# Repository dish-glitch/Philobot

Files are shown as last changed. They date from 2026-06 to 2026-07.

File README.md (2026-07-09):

# Philo — Autonomous Person-Following Robot

**A 4-wheeled ground robot that locks onto a person using real-time YOLOv8 pose detection and follows them across a room. Raise your hand and it stops. Lower it and it follows again.**








---

## Schematic Preview



---

## PCB Preview



---

## Chassis Preview

*Coming soon — Fusion 360 render in progress*

---

## What It Does

A Raspberry Pi 5 runs YOLOv8 pose estimation on a live camera feed, detects the nearest person in frame, and continuously streams direction and speed commands to an ESP32 over UART. The ESP32 runs closed-loop PID speed control on four DC motors via dual H-bridge drivers. Three ultrasonic sensors on the front of the chassis act as an independent safety layer — if an obstacle is detected under 25cm, the ESP32 overrides the Pi command and stops regardless of what the vision stack says.

**Gesture control:** YOLOv8 tracks 17 body keypoints per person. When either wrist keypoint rises above the shoulder keypoint in frame coordinates, the Pi switches to STOP mode and holds it for 5 consecutive frames before acting — this debounces the detection and prevents flickering. Lowering the hand for 5 consecutive frames resumes following. Stop gesture confirmed working in testing.

**Sign language recognition:** The camera detects ASL hand signs in real time using MediaPipe hand landmarks and a trained classifier. Recognized letters are sent over UART to the ESP32 and displayed live on the onboard OLED (bench-tested on the Arduino stand-in; the ESP32 `ASL` handler is implemented and awaiting PCB bring-up). Initial testing on Pi 5 shows strong results for most letters — broader testing across different hands, lighting, and environments is still in progress.

**Obstacle avoidance:** Three HC-SR04 ultrasonic sensors (front-left at -30 degrees, front-center, front-right at +30 degrees) feed into a priority layer in ESP32 firmware. The Pi handles direction. The ESP32 handles not hitting things. These are separate concerns and intentionally kept that way.

---

## How It Works

```
+--------------------------------------------------+
|              Raspberry Pi 5                      |
|                                                  |
|  Camera -> YOLOv8n-pose -> keypoint extraction   |
|               |                                  |
|      Person bounding box offset                  |
|      Wrist vs. shoulder Y position               |
|               |                                  |
|      State machine (FOLLOWING / WAITING)         |
|               |                                  |
|      Serial command -> UART TX                   |
+---------------+----------------------------------+
                |  115200 baud UART
                |  Format: CMD <left> <right> <flags>  (-255..255)
                v
+--------------------------------------------------+
|              ESP32-WROOM-32                      |
|                                                  |
|  UART RX -> parse command                        |
|               |                                  |
|  Ultrasonic check (priority override)            |
|               |                                  |
|  PID speed control per motor side                |
|  PWM via LEDC peripheral at 20kHz               |
|               |                                  |
|  TB6612FNG x2 -> 4 DC motors with encoders      |
+--------------------------------------------------+
```

**Latency budget (targets):**

| Stage | Target |
|---|---|
| Camera capture | ~5ms |
| YOLOv8n-pose inference (imgsz=320) | ~70ms |
| Serial transmission | ~1ms |
| ESP32 motor response | ~5ms |
| **Total loop** | **~80ms (~12 Hz)** |

12 Hz is sufficient for following a walking person. A running person would expose the lag — but that is not the use case.

**Why UART and not I2C or SPI:** UART is asynchronous and trivially debuggable with a serial monitor. I2C requires the ESP32 to act as master which complicates the Pi-side code. SPI is faster than needed. UART at 115200 baud moves our 20-byte command packets in under 2ms. It is the right tool for this interface.

**Why TB6612FNG and not L298N:** The L298N drops ~2V across its internal transistors at 1A, wasting power as heat and requiring a heatsink. The TB6612FNG is a MOSFET H-bridge — nearly zero voltage drop, no heatsink needed, physically smaller. It is the correct motor driver for battery-powered mobile robots.

**Why YOLOv8n-pose and not separate detection and pose models:** One model pass gives you person detection and 17 keypoints simultaneously. Running two models would double inference time and add synchronization complexity. The nano pose model is marginally slower than nano detect-only and eliminates the entire second pipeline.

---

## Hardware

> Prices are estimates. Amazon prices fluctuate — verify before ordering. Order DigiKey parts together to share one flat shipping fee (~$8).

| Component | Purpose | Qty | Est. Price | Where |
|---|---|---|---|---|
| ESP32-WROOM-32 | Main MCU | 1 | ~$5 | Amazon |
| TB6612FNG Dual H-Bridge (bare IC, SSOP-24) | Motor driver (2 motors each) | 2 | ~$2 ea | DigiKey |
| MPU-6050 IMU | Tilt detection, auto-stop on tip-over | 1 | ~$2 | Amazon |
| JGA25-370 Gear Motors w/ Encoders (6V 200RPM) | Drive wheels | 4 | ~$8 ea | AliExpress |
| 80mm Rubber Wheels | Traction | 4 | ~$3 ea | AliExpress |
| HC-SR04 Ultrasonic Sensors | Obstacle detection | 3 | ~$1 ea | Amazon |
| SSD1306 OLED 0.96" I2C | Eyes + ASL display on mast | 2 | ~$4 ea | Amazon |
| 2S LiPo 2200mAh | Main battery | 1 | ~$14 | Amazon / HobbyKing |
| 2S LiPo Balance Charger | Charging | 1 | ~$10 | Amazon |
| Raspberry Pi 5 (4GB) | Vision compute | 1 | on hand | From friend — with active cooler |
| Raspberry Pi Camera Module 3 | 12MP, autofocus | 1 | on hand | Attached, confirmed working |
| AMS1117-3.3 LDO | 3.3V rail for ESP32 logic | 1 | ~$1 | DigiKey |
| Pololu D24V50F5 Buck (5V 5A) | 5V rail for Raspberry Pi | 1 | ~$30 | [Pololu](https://www.pololu.com/product/2851) |
| Littelfuse RGEF700 Polyfuse 7A | Battery overcurrent protection | 1 | ~$2 | DigiKey |
| AOD4185 P-channel MOSFET | Reverse polarity protection | 1 | ~$1 | DigiKey |
| Status LED (any 5mm) | Boot/status indicator | 1 | ~$1 | Amazon |
| Tactile switches 6mm THT | Reset + Boot buttons | 2 | ~$1 | Amazon |
| SMD Resistors 0603 assortment | Pull-ups, current limiting | — | ~$9 | Amazon |
| SMD Capacitors 0603/0805 assortment | HF decoupling bypass caps | — | ~$10 | Amazon |
| Electrolytic caps (1000µF 16V + 2×470µF 16V + 100µF 16V) | Bulk decoupling — order separately, not in SMD assortment | — | ~$5 | DigiKey |
| XT30 Connector Pair | Battery connector | 1 | ~$2 | Amazon |
| 2.54mm Pin Headers | Sensor and UART connectors | — | ~$6 | Amazon |
| CP2102 USB-UART Programmer | Flash ESP32 firmware | 1 | ~$7 | Amazon |
| Custom PCB — JLCPCB (5 boards) | From Gerbers | 1 run | ~$25 | [JLCPCB](https://jlcpcb.com) |
| PETG-CF Filament | Chassis | — | $0 | On hand |
| M2.5 / M3 Standoffs + Screws | Mounting hardware | — | ~$8 | Amazon |
| **Total** | | | **~$215** | |

---

## Repository Structure

```
Philo/
├── hardware/
│   └── kicad/
│       ├── Philo.kicad_sch           # Schematic (ESP32, motors, power, sensors)
│       ├── Philo- main.kicad_pcb     # PCB layout — 116×116mm 2-layer, 4x M3 mounting holes
│       └── gerbers/                  # Production files ready for JLCPCB
│           ├── *.gtl / *.gbl         # Front / back copper
│           ├── *.gts / *.gbs         # Solder mask
│           ├── *.gto / *.gbo         # Silkscreen
│           ├── *.gm1                 # Board outline
│           └── *.drl                 # Drill files
├── firmware/
│   ├── esp32/
│   │   ├── platformio.ini            # PlatformIO config (espressif32 6.9.0)
│   │   └── src/
│   │       ├── main.cpp              # Entry point — 10 Hz sensor + Pi loop
│   │       ├── pins.h                # All GPIO assignments (verified from netlist)
│   │       ├── motors.h / .cpp       # TB6612FNG H-bridge control (PWM via LEDC)
│   │       ├── encoders.h / .cpp     # Interrupt-based wheel encoder counting
│   │       ├── ultrasonic.h / .cpp   # HC-SR04 distance (L / C / R)
│   │       ├── imu.h / .cpp          # MPU-6050 over I²C (accel + gyro)
│   │       ├── display.h / .cpp      # SSD1306 OLED status display
│   │       └── pi_comm.h / .cpp      # UART text protocol to Raspberry Pi
│   ├── arduino/                      # Uno bench-test sketches (ESP32 stand-in)
│   └── pico/                         # Pico MicroPython bench tests (experimental)
├── mechanical/
│   ├── Philo- main.step              # 3D board export
│   ├── fusion360/                    # Chassis CAD source files
│   └── stl/                         # Print-ready STL files
├── vision/
│   └── rpi/                         # YOLOv8 + gesture + ASL + Xbox manual drive (Python)
└── docs/
    ├── images/                       # Photos, renders, wiring diagrams
    ├── PRE_BUILD_LOCK.md             # Design freeze checklist
    └── RESEARCH.md                   # Reference robots, papers, and datasheets used
```

---

## Build Log

| Date | Milestone |
|---|---|
| June 16, 2026 | Project started. Repository initialized. Team of 4 assembled. |
| June 17, 2026 | KiCad schematic started — ESP32, motor drivers, power block |
| June 21, 2026 | PCB schematic complete, ERC clean |
| June 21, 2026 | PCB layout complete, DRC clean, Gerbers exported |
| June 22, 2026 | ESP32 firmware skeleton complete — all modules compile (motors, encoders, ultrasonic, IMU, OLED, Pi UART) |
| June 22, 2026 | Gesture stop function confirmed working (tested on Arduino) |
| June 22, 2026 | Sign language recognition working for subset of letters — OLED display output confirmed |
| June 22, 2026 | Chassis design started in Fusion 360 |
| June 28, 2026 | Upgraded to Raspberry Pi 5 with active cooler — camera confirmed working |
| June 28, 2026 | YOLOv8n-pose running live on Pi 5 — person following confirmed |
| June 28, 2026 | ASL sign recognition working well for most letters in initial testing — broader validation ongoing |
| — | PCB ordered from JLCPCB |
| — | Chassis v1 printed in PETG-CF |
| — | PCB arrived, soldered, power-on test passed |
| — | Basic motor spin confirmed over serial |
| — | First person following on robot hardware |
| — | Gesture control working on robot |
| — | Obstacle avoidance tuned |
| — | Demo video filmed |
| Aug 17, 2026 | School starts — project complete |

---

## Status

- [x] KiCad schematic — complete, ERC clean
- [x] PCB layout — complete, DRC clean, Gerbers exported
- [x] ESP32 firmware skeleton — all modules compile (motors, encoders, ultrasonic, IMU, OLED, Pi UART)
- [x] ESP32 safety layer — 500ms watchdog, obstacle override, tilt cutoff, sequential ultrasonic firing (needs hardware validation)
- [x] Pi vision stack — YOLOv8 person following + gesture + ASL running on Pi 5
- [x] YOLOv8n-pose live on Pi 5 — person following confirmed working
- [x] Gesture stop — confirmed working in bench testing
- [x] ASL sign recognition — working well for most letters in initial testing; broader testing ongoing
- [ ] Gesture sensitivity tuning — currently too sensitive, fix tracked in issue #2
- [ ] PCB fabrication (JLCPCB)
- [ ] Chassis design (Fusion 360) — in progress
- [ ] Chassis printed
- [ ] PID speed loop (ESP32)
- [ ] Ultrasonic obstacle avoidance tuning
- [ ] Full system integration on robot hardware
- [ ] Demo video

---

## Team

| Person | Role |
|---|---|
| [@dish-glitch](https://github.com/dish-glitch) | PCB design (KiCad) + ESP32 firmware |
| [@sivathamizhan](https://github.com/sivathamizhan) & [@dish-glitch](https://github.com/dish-glitch) | Raspberry Pi vision stack — YOLOv8, gesture detection, serial comms |
| [@hummos430](https://github.com/hummos430) | Chassis design in Fusion 360 + 3D printing in PETG-CF |
| [@dish-glitch](https://github.com/dish-glitch), [@hummos430](https://github.com/hummos430), [@sivathamizhan](https://github.com/sivathamizhan) | Mechanical assembly + integration testing |

---

## AI Tools Used

We used Claude (Anthropic) as a reference tool during this project and are disclosing it openly. We had no robotics program, no teacher, and no mentor. AI filled the role a textbook or more experienced teammate would have filled if we'd had access to one.

**Where Claude helped:**

- Reviewing GPIO assignments from the KiCad netlist and catching wiring errors before we soldered anything
- Drafting initial ESP32 firmware modules as a starting point — the team then read through, modified, tested, and debugged everything on actual hardware
- Diagnosing a PlatformIO build failure (`pins_arduino.h` not found) caused by a version conflict between espressif32@6.9.0 and 7.0.1
- Explaining why specific hardware choices make sense (TB6612FNG vs L298N, YOLOv8n-pose vs separate models, UART vs I2C) so we could make informed decisions
- Helping structure the GitHub repository and draft documentation to a presentable structure. 
- Providing weight and dimension constraints for the chassis — specifically, what size the enclosure needs to be so the motors can actually move it. The chassis itself is fully designed by the team in Fusion 360

**What the team built and owns:**

- All hardware decisions — component selection, schematic design, and PCB layout in KiCad
- The full vision stack — YOLOv8 inference pipeline, ASL classifier, gesture detection, serial comms — written and tested by the team
- All physical testing and iteration — every debug session, hardware fix, and tuning pass was done by us in the real world
- The chassis design in Fusion 360 — built by our mechanical lead from scratch
- Every journal entry — written by the team in our own words

We are happy to answer questions about any part of this project. We have used AI to help build it, but we understand everything we built. If AI helped create any line of code or suggested a part that seemed better, we did the research to understand what that part or code does and why — before it went into the project. The reference robots, papers, and datasheets we used to back up those decisions are collected in [`docs/RESEARCH.md`](docs/RESEARCH.md).

---

## License

MIT — use, modify, share freely. See [LICENSE](LICENSE).

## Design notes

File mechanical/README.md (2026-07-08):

# Mechanical — Philo Chassis

**Owner: [@hummos430](https://github.com/hummos430) [@ezan13](https://github.com/ezan13)         **

---

## Overview

Philo uses a differential drive system — 4 wheels, split into a left side and a right side. Both wheels on the left are driven together, both wheels on the right are driven together. Turning is done by spinning the two sides at different speeds or in opposite directions. No steering axle, no servo, no complex geometry. Same drive principle as a tank or a wheelchair.

---

## How Turning Works

| Command | Left Side | Right Side | Result |
|---|---|---|---|
| Forward | Forward | Forward | Straight |
| Turn Right | Forward | Slower / Reverse | Curves or pivots right |
| Turn Left | Slower / Reverse | Forward | Curves or pivots left |
| Spin in Place | Forward | Reverse | Zero-radius pivot |
| Stop | Stop | Stop | Brakes |

The ESP32 controls each side independently via PWM. hummos430 does not need to worry about the electronics — just make sure the left two wheels are each driven by their own motor and the right two are each driven by theirs. The cable from each motor goes straight to the PCB.

---

## Real Weight Budget (Verified Component Weights)

> This section uses confirmed specifications from datasheets and product pages. These are not guesses.

| Component | Source | Confirmed Weight |
|---|---|---|
| Raspberry Pi 5 (4GB) w/ active cooler | Official spec | **51g + ~15g cooler = ~66g** |
| Pi Camera Module 3 | Manufacturer spec | **4g** |
| ESP32-WROOM-32 module | Espressif datasheet | **2.5g** |
| HC-SR04 ultrasonic x3 | Product spec, 10g each | **30g** |
| MPU-6050 GY-521 module | Product spec | **13g** |
| TB6612FNG motor driver x2 | [Pololu spec](https://www.pololu.com/product/713/specs), 1.5g each | **3g** |
| 2S LiPo 2200mAh (Gens Ace soft pack) | Manufacturer spec | **97-130g -> use 110g** |
| Custom PCB (bare board + soldered components) | Estimated from board size and part count | **50g** |
| 4x JGA25-370 gear motors | Product spec, 90g each | **360g** |
| 4x 80mm rubber wheels with hubs | Typical for this wheel diameter | **30g each -> 120g** |
| Camera mast (PETG-CF printed) | Calculated from geometry | **~30g** |
| PETG-CF chassis (all printed parts, see calculation below) | Calculated from geometry and density | **~180g** |
| Wiring, connectors, cable ties | Measured estimate | **50g** |
| M2/M2.5/M3 standoffs and screws | Hardware kit estimate | **30g** |
| **Total** | | **~1048g** |
| **Design target with 15% margin** | | **~1.2kg** |

**Why 15% margin:** Wiring estimates are imprecise. Small additions (heatsinks, extra connectors, zip ties) accumulate. Design and test everything assuming 1.2kg. If the robot comes in lighter, it only moves faster.

### PETG-CF Chassis Weight Calculation

PETG-CF density: ~1.27 g/cm3 (from filament datasheet)

Estimated printed volume breakdown for 300mm x 220mm chassis:
- Base plate (300x220x5mm at 20% infill, 4 walls): ~60 cm3 of material
- 4x motor mounts (40x30x25mm each, 35% infill): ~30 cm3
- Side rails, cable guides, misc: ~20 cm3
- **Total material: ~110 cm3 x 1.27 g/cm3 = ~140g -> round to 180g with connectors and inserts**

If hummos430 runs the print and it comes in heavier than 200g, reduce infill on non-structural panels or add pocketing to the underside of the base plate.

---

## Motor Selection — Verified Analysis

**Selected motor:** JGA25-370 gear motor, 6V, 200 RPM, with encoder

**Why not N20 motors:** N20 motors are the right choice for a lightweight mini robot (~650g). For Philo at 1.2kg on a larger chassis, N20 stall torque (~0.7 kg·cm) gives very little safety margin on carpet. The JGA25-370 is the appropriate upgrade — 25mm body diameter, 4mm D-shaft, rated stall torque ~2.0 kg·cm. Still small enough to fit in the chassis without making it a forklift.

**Note on voltage and actual speed:** The motors are rated at 6V. Powered from 2S LiPo at 7.4V nominal, they run at ~7.4/6.0 = 1.23x rated speed = ~246 RPM. With 80mm wheels:

| Motor | Rated | At 7.4V | Speed on 80mm wheel | Notes |
|---|---|---|---|---|
| JGA25-370 200 RPM | 6V, 200 RPM | 246 RPM | **0.52 m/s** | Good following speed for demo |
| JGA25-370 100 RPM | 6V, 100 RPM | 123 RPM | 0.26 m/s | Too slow |
| JGA25-370 300 RPM | 6V, 300 RPM | 369 RPM | 0.77 m/s | More speed, less torque — carpet risk |

200 RPM at 6V is the correct choice. Demo following speed is typically 0.3-0.6 m/s. The robot will have speed margin in reserve for correction turns.

### Torque Analysis — Will the Motors Move This Robot?

**Worst-case surface: carpet (rolling resistance coefficient ur = 0.15)**

Total rolling resistance force the motors must overcome:
```
F_resist = ur x mass x g
F_resist = 0.15 x 1.2 kg x 9.81 m/s^2
F_resist = 1.77 N
```

Force required per side (2 sides of the drivetrain):
```
F_per_side = 1.77 / 2 = 0.885 N
```

Torque required per motor (2 motors per side, 80mm wheel = 0.040m radius):
```
t_required = F_per_side x wheel_radius / motors_per_side
t_required = 0.885 x 0.040 / 2
t_required = 0.0177 N*m = 1.77 N*cm = 0.18 kg*cm per motor
```

**JGA25-370 200 RPM at 6V specs (verified range from product pages):**
- Stall torque: 1.8-2.2 kg*cm (use 1.8 kg*cm conservative)
- Stall current: 1.0-1.8A per motor at 6V (at 7.4V: ~1.2-2.2A)
- No-load current: 80-120mA per motor

Pololu recommends operating motors at no more than 25% of stall torque for long-term reliability:
```
Continuous safe torque = 0.25 x 1.8 kg*cm = 0.45 kg*cm per motor
```

**Required 0.18 kg*cm vs. safe continuous 0.45 kg*cm**

The motors are running at **40% of their safe continuous rating** on carpet. On smooth floor (ur = 0.02), load drops to about 5% of safe rating. The motors will not overheat under normal following conditions.

### Startup Torque (Starting from a Stop)

Static friction is roughly 2x rolling friction. Worst case startup on carpet:
```
t_startup = 0.18 x 2 = 0.36 kg*cm per motor
```
Still under the 0.45 kg*cm safe continuous limit. The robot will start from rest on carpet without stalling.

### Motor Driver Thermal Note

The TB6612FNG is rated for 1.2A continuous per channel. JGA25-370 running current at 40% load is approximately 0.4-0.6A per motor — well within the limit. However, at brief stall (firmware watchdog not yet triggered), stall current at 7.4V could reach 1.5-2.2A per motor, which exceeds the 1.2A continuous rating. The 3.2A peak rating handles this for brief moments.

**Ensure the TB6612FNG KiCad footprint has its exposed thermal pad connected to a copper pour for heat dissipation.** If the IC gets too hot to touch during testing, add a small heatsink or increase copper pour area under the chip.

---

## Target Dimensions

| Parameter | Target |
|---|---|
| Footprint | 300mm (L) x 220mm (W) |
| Chassis body height | 80-100mm |
| Ground clearance | 15mm minimum |
| Wheel diameter | 80mm |
| Wheelbase (front to rear axle) | ~200mm |
| Track width (left to right wheel center) | ~190mm |
| Camera total height from ground | ~380mm |

Ground clearance: 15mm minimum clears most carpet pile and small floor obstacles.

---

## Center of Gravity — Where to Place Components

The battery (110g) and motors (360g) are the heaviest components. Motor weight is distributed at all four corners by design — the CG problem is the battery.

**Battery:** As low as possible. Centered between front and rear axles. If it sits too far back, the robot lifts its front wheels slightly on forward acceleration — the camera tilts up and loses the person. If too far forward, braking causes front-dip.

**Raspberry Pi 5 (66g with active cooler):** Mount flat in the middle of the chassis, centered left-to-right. Keeps weight balanced.

**PCB (50g):** Can sit on top of or beside the Pi. Keep it centered.

**Camera mast (30g):** Light enough to not affect CG significantly, but keep the mast rigid — flex in the mast causes the camera to bounce during movement, which blurs frames and confuses YOLO.

**General rule:** Dense things (battery, PCB) go low and center. The mast should be bolted to the chassis plate, not cantilevered off the Pi case.

---

## What Needs to Be Designed in Fusion 360

### 1. Main Chassis Plate
Flat structural base. Everything mounts here.

Required features:
- 4x motor pocket cutouts or brackets (one per corner)
- 4x M3 through-holes for PCB standoffs. Board is **116mm × 116mm**. Hole centers, measured from the PCB's own top-left corner (X right, Y down, matching the KiCad board outline origin):

  | Hole | X (mm) | Y (mm) |
  |---|---|---|
  | A | 6.68 | 6.42 |
  | B | 109.76 | 6.02 |
  | C | 5.52 | 110.14 |
  | D | 109.34 | 109.53 |

  Holes are hand-placed near each corner, not a perfect symmetric grid — use these exact coordinates, not an estimated pattern.
- 4x M2.5 through-holes for Raspberry Pi — 58mm x 49mm hole pattern (official Pi spec, not approximate)
- Battery bay: 90mm x 36mm x 22mm minimum clearance for a soft-pack 2200mAh LiPo. Add a strap mount or lip to hold the battery in during sharp turns.
- 3x sensor cutouts or pockets on front face for HC-SR04 (body size 45mm x 20mm x 15mm per sensor). One center, one angled left 30 degrees, one angled right 30 degrees.
- Mast mounting point: 4x M3 holes in a square pattern, centered at front-middle of chassis, for the camera mast base
- Cable routing channels on underside — wires should not run near wheel path

### 2. Motor Mounts
**Motor body: JGA25-370 — 25mm diameter, mounting holes M3, 17mm center-to-center spacing (verify with calipers on actual motor before printing)**

- Hold JGA25-370 motor body rigidly at each corner, shaft pointing outward
- Use M3 screws through motor mounting holes (two per motor)
- Motor sits as low as possible so wheel center is at the correct height for 15mm ground clearance
- Leave 0.4mm clearance around motor body (not zero — PETG-CF shrinks slightly on cooling, and the JGA25-370 has a round cylindrical body that needs clearance to slide in)
- **Print orientation: motor mounting face must be a horizontal print surface, not a bridged overhang**

### 3. Wheel Hubs (if not included with purchased wheels)
**JGA25-370 uses a 4mm D-shaft. This is different from the N20 (3mm D-shaft). If any existing hub files use 3mm, they need to be updated.**

- Bore for 4mm D-shaft: 4.0mm round + 0.5mm flat on D-side
- Press-fit tolerance: 0.0mm on shaft diameter (tight fit, may need light sanding)
- Print at 100% infill — this part transmits all motor torque
- **Print orientation: flat of the D-bore must be vertical for maximum layer adhesion in torque direction**

### 4. Camera Mast
**This is the most important structural addition and directly affects whether gesture detection works.**

The camera must be elevated to see the person's torso and arms, not their knees.

Required geometry:
- Mast height: 200mm above the chassis plate (camera will be at ~280-300mm from ground, +80mm chassis = ~380mm total)
- Camera angle: 20-25 degrees upward from horizontal (tilted up)
- Camera mount at top of mast: 25mm x 24mm PCB holder, 4x M2 mounting holes in 21mm x 12.5mm pattern
- Mast base: bolt plate with 4x M3 holes matching chassis mounting point
- Cross-section: 20mm x 20mm minimum (thicker is stiffer — mast flex causes camera to bounce)
- Add a gusset brace from mast to chassis plate if the mast extends more than 180mm — prevents forward/backward flex during acceleration

Why this height and angle (calculation):
```
Camera at 380mm height, tilted 25 degrees upward, 1.5m from person:
- Bottom of camera frame hits: 380mm + 1500mm x tan(0.6 degrees) = ~396mm from ground (knee height)
- Center of frame hits: 380mm + 1500mm x tan(25 degrees) = 1079mm from ground (mid-torso)
- Top of frame hits: 380mm + 1500mm x tan(49.4 degrees) = ~2130mm (above head)
```
At 1.5m, the camera sees from knee height to above the head — wrists and shoulders are visible. Gesture detection works.

Secure the CSI ribbon cable with a cable clip within 20mm of each connector — prevents the ribbon from pulling on connectors when the robot turns.

### 5. Ultrasonic Sensor Mounts
Three HC-SR04 sensors on the front face. 
To determine what angle to place the side sensors, we used the following equation
Width = 2* Distance * tan (theta/2). 
Since the HC-SR04 has a beam angle of 15deg, at 1m away, the detection width of one sensor is about 0.26m. At 4m away, the detection width of one sensor is about 1.05m. 

Based on this information, we finalized with the following sensor positions: one centered (pointing straight ahead), one angled 15 degrees left, and one angled 15 degrees right. Body size: 45mm x 20mm x 15mm. Leave room for the connector to plug in from above.

### 6. Top Cover (Low Priority — Week 7+)
Cosmetic only. Design after all mechanical integration is verified.

---

## Print Settings

**Material:** PETG-CF (already on hand)

| Setting | Structural Parts (mounts, hubs, mast) | Chassis Plate and Covers |
|---|---|---|
| Nozzle temp | 245 C | 240 C |
| Bed temp | 75 C | 70 C |
| Infill | 35-40% | 20-25% |
| Wall perimeters | 4 | 4 |
| Layer height | 0.2mm | 0.2mm |
| Nozzle type | Hardened steel required | Hardened steel required |

**Nozzle note:** CF filament is abrasive. Standard brass nozzles wear within a few hundred grams of CF filament. Use hardened steel.

**Print orientation — motor mounts specifically:**
The torque from the motor tries to peel the mount apart along its layer lines. The mount must be oriented so the primary load direction is perpendicular to the layer lines (i.e., load tries to compress layers together, not split them apart).

**Print orientation — camera mast:**
Print vertically (mast standing upright). This puts the layer lines horizontal, which resists forward/backward bending loads from camera weight and robot acceleration. If the mast is printed on its side, layers run vertically and the mast can snap at a layer line under load.

---

## Failure Modes to Avoid

| Risk | Cause | Prevention |
|---|---|---|
| Motor mount cracks under torque | Wrong print orientation — layers split along line of force | Orient mount so load compresses layers, not separates them |
| Wheel hub slips on shaft | Insufficient interference fit (note: 4mm D-shaft, not 3mm) | Print hub at 100% infill, measure bore with calipers before assembly |
| Ground clearance lost | Chassis plate sags under component weight | 4 perimeter walls on base plate, 20% infill minimum |
| CSI ribbon cable disconnects | Vibration on cable with no strain relief | Zip tie cable within 20mm of both connectors |
| Camera mast flex causes frame blur | Mast too thin, cantilevered off light mounting point | 20mm x 20mm minimum cross-section, gusset brace at base, bolt directly to chassis plate |
| PCB standoffs misaligned | Drilling positions confirmed before print | Get M3 hole positions from hardware team before finalizing chassis |
| Battery ejects during turn | No battery retention | Add lip or strap mount in the bay |
| JGA25-370 wrong shaft size in hub | Old N20 hub design (3mm bore) reused | Confirm 4mm D-shaft bore in Fusion 360 before printing hubs |

---

## Coordination Points with Hardware Team

**Hard dependencies before printing the final chassis:**

| What to Confirm | Why |
|---|---|
| PCB outer dimensions and M3 hole positions | Standoffs drilled in wrong place = reprint |
| Motor type (confirm JGA25-370 body diameter and M3 hole spacing — measure with calipers) | Motor pocket dimensions depend on exact motor body |
| Battery pack dimensions (get physical dimensions of the actual battery ordered) | Bay sizing |
| HC-SR04 body dimensions (should be 45mm x 20mm x 15mm but verify) | Sensor pocket sizing |
| Camera mast mounts (confirm M2 hole pattern from Pi Camera Module 3 spec before designing top of mast) | 21mm x 12.5mm pattern per spec, but verify |

Resolve all of these with the hardware team before end of Week 2.

---

## Timeline

| Week | Target |
|---|---|
| 1-2 | Sketch top-down footprint, confirm motor and battery dimensions, rough layout in Fusion 360 |
| 2 | Coordinate M3 PCB standoff positions with hardware team |
| 3 | Final chassis v1 ready to print — all dimensions confirmed |
| 4 | Chassis v1 printed, test-fit motors, PCB, and Pi before any permanent assembly |
| 4 | Print camera mast, verify camera height and angle geometry |
| 5-6 | Revisions based on integration testing |
| 7 | Final chassis, strain relief, cable routing complete |

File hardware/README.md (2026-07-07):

# Hardware — Philo PCB

**Owner: [@dish-glitch](https://github.com/dish-glitch)**

---

## Overview
The PCB was designed as the main interface for philo, it distributes the power and connects the raspberry Pi and ESP32. It drives the motors, and provides connectors for the sensors used throughout the robot. 

**Current phase: PCB fabrication.** Schematic complete (0 ERC errors), PCB layout complete (DRC clean, Gerbers exported). Kicad files: [`hardware/kicad/`](kicad/).

**For the actual build, start here:**
- **[BOM.md](BOM.md)** — complete parts list 
- **[SCHEMATIC.md](SCHEMATIC.md)** — completed, for reference

---

## Component Specifications (Verified from Datasheets)

The components below are the parts selected for the current revision of the PCB. Main componets are here incase of debugging. 

| Component | Key Specs | Source | Weight |
|---|---|---|---|
| ESP32-WROOM-32 | 240MHz dual-core, 520KB SRAM, 3.3V, 18x25.5x3.1mm | [Espressif datasheet](https://www.espressif.com/sites/default/files/documentation/esp32-wroom-32d_esp32-wroom-32u_datasheet_en.pdf) | 2.5g |
| TB6612FNG x2 | 1.2A continuous / 3.2A peak per channel, 4.5-13.5V motor, 2.7-5.5V logic, 100kHz PWM max | [Toshiba datasheet](https://cdn-shop.adafruit.com/datasheets/TB6612FNG_datasheet_en_20121101.pdf) | 1.5g each |
| MPU-6050 (GY-521 module) | 3-axis accel +/-16g, 3-axis gyro +/-2000 deg/s, I2C, 3.3-5V, 21x15mm | [InvenSense datasheet](https://product.tdk.com/en/search/sensor/mortion-inertial/imu/info?part_no=MPU-6050) | 13g |
| HC-SR04 x3 | 5V, <15mA, 2-400cm range, 40kHz, 45x20x15mm | [Sparkfun datasheet](https://cdn.sparkfun.com/datasheets/Sensors/Proximity/HCSR04.pdf) | 10g each |
| AMS1117-3.3 LDO | 3.3V out, 800mA max, SOT-223 package | AMS datasheet | <1g |
| Pololu D24V50F5 Buck (5V/5A) | 4.5-38V in, 5.0V fixed out, 5A continuous near capacity with Pi 5 (up to 4.5A peak) | [Pololu D24V50F5](https://www.pololu.com/product/2851) | ~5g |
| JGA25-370 x4 | 6V, 200 RPM, 1.8-2.2 kg*cm stall torque, 4mm D-shaft, 25mm body diameter | Product page | 90g each |
| 2S LiPo 2200mAh | 7.4V nominal, 8.4V full, 6.4V cutoff, 97-130g depending on model | Gens Ace product page | ~110g |
| XT30 Connector | 30A continuous, gold plated, compact | XT30 spec | 3g per pair |

---

## PCB Block Architecture

### Block 1 — Microcontroller: ESP32-WROOM-32

the ESP32 is responsible for the robot's real time control. it hands the motor control, reads the ultrasonic sensors and IMU. it also communicates with the PI over UART and updates the oled screens. 

**Decoupling:** we placed one 100nF ceramic cap and one 10uF electrolytic cap between VCC and GND, as close to the module as possible. These capacotors help keep the esp32 stable during current changes. 

**Brownout detection:** we enabled the ESP32 hardware brownout detector in firmware and set brownout threshold to 2.7V via esp_reset_reason and brownout config. This allows the esp32 to reset cleanly rather than staying in an undefined state. 

**Programming:** 6-pin header (TX, RX, EN, GPIO0, 3.3V, GND). CP2102 plugs in here!

Boot button: tactile button from GPIO0 to GND needed for entering flash mode. 

### Block 2 — Motor Drivers: TB6612FNG x2 

Two TB6612FNG ICs. Each drives two motors. Total: 4 motors driven.

**Why we chose the TB6612FNG:** Early in the project we were going to pick the L298N becuase its common and used in many starting projects, but after looking at the voltage drop and power loss we decided to use the TB6612FNG. Because it uses MOSFET instead of bipolar transistors it wastes less power while aslo delivering more of the battery voltage to the motors.  

**Wiring each TB6612FNG:**
- PWMA, AIN1, AIN2 from ESP32 GPIO
- AO1, AO2 to motor A terminals
- PWMB, BIN1, BIN2, BO1, BO2 for motor B
- STBY tied HIGH (3.3V) permanently — LOW disables all outputs
- VM to VBAT (motor voltage, up to 13.5V)
- VCC to 3.3V logic

**TB6612FNG thermal note with JGA25-370 motors:** The JGA25-370 at 7.4V running at 40% load draws ~0.5A per motor. However, at brief stall (before the firmware watchdog triggers at 500ms), stall current at 7.4V can reach 1.5-2.2A per motor, exceeding the 1.2A continuous rating but within the 3.2A peak. The IC handles this for brief moments. Ensure the TB6612FNG KiCad footprint has its exposed thermal pad connected to a GND copper pour on the PCB. This provides a thermal path from the die to the board. If either IC is hot to the touch after Test 2 (repeated reversals), increase the copper pour area under the chip.

**Back-EMF on motor reversal:** we also found that the when motor is commanded to reverse direction mid-spin, it briefly acts as a generator. This creates a voltage spike back into the VM pin. The TB6612FNG has internal flyback diodes on all output transistors that clamp this spike to VM. The 470uF bulk cap at each TB6612FNG VM pin (see Section: Ground Architecture and Decoupling) further absorbs these transients.

**Placement:** Both TB6612FNG ICs on the same side as motor output connectors. Motor output traces (AO1, AO2, BO1, BO2) minimum 1.2mm. Short and direct to connectors.

### Block 3 — Power Architecture

The main power system. This is one of the most important parts of the PCB due to its important purpose of reliablly supplying power to the raspberry pi, esp32, motors, and the sensors.  

**Input: 2S LiPo via XT30**

Voltage range: 6.4V (discharged) to 8.4V (fully charged). 7A-rated polyfuse on input line (e.g., Littelfuse RGEF700) — trips at sustained overcurrent, resets after cooldown. P-channel MOSFET for reverse polarity protection.

**Why 7A, not 5A:** A polyfuse has nonzero resistance that increases as it heats up. A 5A-rated polyfuse at 3A normal load runs warm and its resistance rises to 0.1-0.5 ohm, causing 0.3-1.5V sag on VBAT before it ever trips. A 7A-rated part runs cold at our 3A normal current (resistance stays in milliohm range), so there is no sag during operation. Protection still works — fault currents above 7A trip it cleanly.

**3.3V Rail: AMS1117-3.3 LDO**

Powers: ESP32, MPU-6050, TB6612FNG logic, sensor pull-ups, LEDs.

**Input: 5V rail (from D24V50F5 output) — NOT from VBAT directly.**

Reason: At 8.4V VBAT input, the AMS1117 dissipates (8.4 - 3.3) x 0.27A = 1.38W. In SOT-223, that is a junction temperature of ~135C at 25C ambient, which is at or above the 125C maximum rating. Fed from 5V instead, dissipation is (5.0 - 3.3) x 0.27A = 0.46W, estimated junction temperature ~62C. Safe.

One reviewer concern was that cascading from 5V "couples Pi rail noise into ESP32 rail." This is overstated: the AMS1117 is a linear regulator with ~65dB PSRR at low frequencies, meaning 5V ripple is attenuated 1800x at the 3.3V output. If the 5V rail sags badly enough to matter for ESP32, the Pi is already browned out — that is a separate problem addressed by the 1000uF cap.

Caps: 10uF electrolytic + 100nF ceramic on both input and output pins. Required for AMS1117 stability — without them the output oscillates at high frequency.

Max load: ~270mA. Rated 800mA. Adequate headroom.

**5V Rail: Pololu D24V50F5 Buck Converter (5V, 5A)**

> Revision history: MP2307 (1.2A) was the original part — far too small, would have burned out. Then MP1584EN (3A) — adequate but tight: Pi at 2.5-3.0A + AMS1117 cascade 0.27A = ~2.77A on a 3A part, marginal once derated for an enclosed chassis. Final part is the **D24V50F5 (5A)** for real headroom on the most demo-critical rail. Pi brownout is the #1 demo-killer, so this rail gets margin.

Input: VBAT (6.4-8.4V)
Output: 5.0V (fixed — no trimpot to set, unlike the MP1584EN module)
EN pin: tie to VIN or leave floating (internal pull-up enables by default). PG (power-good) pin optional.

**Total 5V load: Pi 3.5A typical (4.5A peak) + AMS1117 cascade 0.27A = ~3.77A typical.** D24V50F5 rated 5A. At peak Pi load the margin is only ~0.5A — monitor for throttling during full inference. Active cooler on the Pi 5 mitigates thermal throttling and reduces average power draw.

**Output capacitors — updated from earlier revision:**
- 1000uF electrolytic (upgraded from 100uF based on Pi inrush spike analysis)
- 100nF ceramic in parallel

Why 1000uF: When the Pi 5 CPU ramps from idle to full inference load, it draws a current spike faster than the converter's control loop can respond (~microseconds). The 1000uF cap supplies that spike locally while the converter catches up. At a 3A spike for 1ms, 1000uF holds the voltage within 3mV of setpoint. 100uF would sag by 30mV — enough to trigger the Pi's undervoltage warning. Keep this cap even with the 5A buck 

5V connects to Pi via 2-pin header to GPIO pin 2 (5V) and pin 6 (GND). 

**Power sequencing note:** ESP32 boots in ~300ms. Pi takes 20-30 seconds. Firmware default state: all motors stopped, watchdog running. Motors do not move until first valid CMD packet received from Pi.

### Block 4 — Ground Architecture and Decoupling

While reviewing the power system, I realized the PCB layout mattered just as much as the schematic. Most of the components were already connected correctly, but poor grounding can still cause random resets and communication issues

**The problem:** Motor switching at 20kHz creates high-frequency current spikes through the ground path. If motor return current and ESP32 ground share any trace segment, the voltage difference across that trace's resistance injects noise into the ESP32's ground reference. This causes:
- Ghost resets when motors start or reverse
- UART data corruption on sharp direction changes
- Ultrasonic echo timing errors during motor switching
- IMU readings spiking during acceleration

**The fix — ground plane:**

Use the bottom copper layer as a solid ground plane. In KiCad: copper fill on back copper layer, set to GND net, pour.

This gives all ground connections (motor return, ESP32 GND, sensor GND, LDO GND) a low-impedance path back to the battery negative terminal.

**Single star point:** The battery negative (GND from XT30) should be the first ground connection on the board. Everything else connects to the plane, which connects to this point. 

**Bulk capacitors at each TB6612FNG:**

we have one 470uF electrolytic capacitor directly at each TB6612FNG VM pin (motor supply voltage). These absorb the current spike when a motor starts from rest or reverses direction. Without them, the spike travels back to the battery and couples into the 3.3V and 5V rails through shared impedance.

Component count: 2x 470uF (one per TB6612FNG IC), placed within 3mm of the VM pin.

**Decoupling cap placement rules:**
- 100nF ceramic caps: within 2mm of every IC power pin
- 470uF motor bulk caps: within 3mm of TB6612FNG VM pins
- 1000uF Pi rail cap: within 5mm of D24V50F5 output
- All caps connect to ground plane via short vias, not via trace segments

### Block 5 — IMU: MPU-6050

Connects via I2C (SDA/SCL). Default address 0x68. Document I2C address map.

Mount flat and horizontal on the PCB. 4.7k pull-ups on SDA and SCL to 3.3V. ESP32 internal pull-ups are too weak for reliable I2C.

Implement I2C bus recovery routine in firmware (9 SCL clocks with SDA held high) to clear SDA-stuck-low lockups from Pi resets mid-transaction.

**I2C address map (three devices on one bus):**

| Device | I2C Address | Function |
|---|---|---|
| MPU-6050 | 0x68 | Tilt / tip-over detection |
| OLED left eye | 0x3C | Companion display |
| OLED right eye | 0x3D | Companion display |

The bus has 4.7k pull-ups which should be adequate for all three devices on a short bus (under ~15cm total trace length). Keep the I2C traces short and route them away from motor traces.

### Block 5b — Companion Display: 2x OLED Eyes

Philo is a companion robot, so it has an animated face. Two SSD1306 (or SH1106) OLED modules, 128x64, I2C, mounted at the top of the camera mast as eyes.

- Addresses 0x3C and 0x3D, set by the address-select pad on each module (most SSD1306 breakouts have a solderable jumper to pick 0x3C or 0x3D)
- Power: 3.3V, ~20mA each (~40mA total) — negligible
- Driven by the ESP32 on core 1 (see firmware README — full refresh is ~23ms per display, so it must NOT run in the control loop)
- Connect via the existing I2C bus — no new GPIO pins needed

**Mechanical:** hummos430 needs two OLED-sized cutouts in the front of the camera mast head, positioned as eyes. OLED active area is ~22mm x 11mm; module PCB is ~27mm x 27mm. Mount with M2 screws or a friction pocket.

### Block 5c — Audio: handled by the Raspberry Pi, NOT the ESP32

Sound (personality chirps, "found you" / "waiting" clips) is driven by the Raspberry Pi, not the ESP32.

**Why not the ESP32:** the ESP32 is nearly out of usable GPIO. The only free pins (0, 12, 15) are all boot-strapping pins, which makes driving an I2S speaker amp off them fragile. The Pi has free USB ports, a filesystem for WAV clips, and trivial audio playback (aplay). It also already knows the high-level state (found/lost/gesture) that should trigger sounds.

**Hardware (Pi side, not on this PCB):**
- A cheap USB audio adapter + small amplified speaker, OR a small self-powered USB speaker
- Powered from the Pi USB port (small speaker) or tapped from the 5V rail (budget ~600mA peak, intermittent — see power budget)

### Block 6 — Ultrasonic Sensors: HC-SR04 x3

Mount on chassis, connect via 4-pin headers. Echo pins MUST go through voltage dividers before reaching ESP32 GPIO — HC-SR04 echo is 5V, ESP32 max input is 3.6V.

```
HC-SR04 Echo (5V) ---- 1k ----+---- ESP32 GPIO (3.33V)
                               |
                              2k
                               |
                              GND
```

Here is the calculation for this :D
Vout = Vin × R2/(R1+R2)

= 5V(ECHO pin) × 2k/(1k+2k)

= 3.33V

**HC-SR04 crosstalk** if we fire all of the sensors at once for example: If sensor A fires while sensor B is listening, sensor B will hear sensor A's pulse as a reflection and report a obstacle a few centimeters away even though there is no obstacle causing the esp32 stop. we made the firmware fire sensors sequentially with a 60ms delay between each that way it it eliminates the risk of ghost stopping. See firmware README for timing diagram.

**Cable routing for sensor wires:** we have to keep the HC-SR04 cables short (under 20cm). Motor PWM switching creates noise on the ultrasonic signals when the wires were routed together so we plan to make srue the sensor wires are away from the motor wires to reduce false reading. 

### Block 7 — Brownout Visibility

indecators to help find out why something has stopped working. 

**Status LED behavior (firmware controls this, but hardware must support it):**
- Solid ON: normal operation
- Fast blink (5Hz): low battery warning (below 6.4V)
- Double flash pattern: ESP32 reset from brownout
- Off: power loss

**Battery sense circuit (add to schematic):**

A resistor divider from VBAT to an ESP32 ADC pin lets the firmware monitor battery voltage:

```
VBAT ---- 10k ----+---- ESP32 ADC (GPIO36, input-only pin)
                  |
                 3.3k
                  |
                 GND
```

At 8.4V battery: ADC reads 8.4 x (3.3/(10+3.3)) = 2.08V
At 6.4V battery: ADC reads 6.4 x (3.3/(10+3.3)) = 1.58V

Both within ESP32 ADC range (0-3.3V). When the ADC reading drops to the value corresponding to about 6.4V battery voltage, the firmware warns the user and can disable high-current operations.

---

## Power budget 

| Component | Voltage Rail | Typical Current | Peak (transient) | Source | 
|---|---|---|---|---|
| Raspberry Pi 5 w/ active cooler (inference load) | 5V | 3.5A | 4.5A | Raspberry Pi 5 requires more power than our original Pi 4 plan, especially during AI inference. The 5V convertor is reaching its limit so we plan to monitor it. -- this is a estimate.  |
| 4x JGA25-370 motors (running load at 40% torque) | VBAT | 2.0A total | 8.8A (The polyfuse is only a backup safety layer. It is not expected to handle normal motor stalls because the firmware watchdog should disable the motors first.) | Motor spec + stall analysis |
| 4x JGA25-370 motor reversal transient | VBAT | — | ~4.4A for <50ms | Back-EMF analysis (2 motors reverse at once) |
| ESP32 (active, WiFi off) | 3.3V | 240mA | 340mA | Espressif datasheet |
| 3x HC-SR04 | 5V | 45mA | same | HC-SR04 datasheet |
| MPU-6050 | 3.3V | 3.9mA | same | InvenSense datasheet |
| 2x OLED eyes | 3.3V | 40mA | same | SSD1306 spec |
| Speaker (Pi-side, if on 5V rail) | 5V | 50mA idle | ~600mA peak (intermittent) | MAX98357A / USB speaker spec |
| Misc (LEDs, pull-ups) | 3.3V | 20mA | same | Estimated |
| **Total normal operation** | | ~4.8A | | |
| **Motor reversal transient** | | | ~4.4A for <50ms | Absorbed by 470uF caps |
| **All motors stalled** | | ~8.8A sustained | | Above 7A hold — polyfuse trips slowly; firmware watchdog (500ms) is primary stall protection |

**Note on speaker peak:** the ~600mA speaker peak is brief (during a sound clip) and stacks on the 5V rail. With the 5A D24V50F5, total worst case (~3.77A typical + 0.6A = ~4.4A) still fits under the 5A rating.

**Battery runtime:** we estimated that the battery can run for about 27 minutes.  2200mAh x 7.4V = 16.3Wh. At ~35W normal draw: ~27 minutes. 

**Polyfuse behavior at all-motors-stall:** 4x JGA25-370 at 7.4V stall current ~1.5-2.2A each = 6-8.8A total. The RGEF700 (7A hold, ~14A trip current) at 8.8A is only 1.26× hold — it will trip but slowly (minutes, not seconds). This is intentional: the 7A part was chosen over 5A specifically to avoid pre-trip resistance sag at normal 3A load. At stall, the firmware 500ms watchdog stops the motors long before the polyfuse acts. The polyfuse is the last-resort backstop for a firmware crash, not the primary stall protection.

**Motor reversal transient:** During reversal, motor acts as generator. Two motors reversing simultaneously gives ~4.4A transient for <50ms. Two 470uF caps at TB6612FNG VM pins (one per IC) absorb this: 0.47 coulombs capacity, transient requires 0.22 coulombs. This calculation was done as a rough check to verify the capacitors were large enough to reduce voltage dips during motor direction changes.

---

## Trace Width Requirements

| Net | Max Current | Minimum Width | Notes |
|---|---|---|---|
| VBAT input | 9A peak (stall) | 2.5mm | Size for fault condition |
| Motor outputs (per TB6612FNG channel) | 1.2A cont, 3.2A peak | 1.2mm | Short, direct to connector |
| 5V RPi rail | 3A | 1.5mm | Full Pi inference current |
| 3.3V logic rail | 500mA | 0.8mm | Include margin |
| Signal traces (UART, I2C, GPIO) | <50mA | 0.25mm | KiCad default |

---

## Electrical Stress Test Protocol

Before trusting any demo, run these tests in order. If the robot passes all four, the power system is solid.

**Test 1 — Full throttle forward for 30 seconds**
Command `CMD 255 255 0`. Measure battery voltage at start and end. Should not sag more than 0.3V. Feel the TB6612FNG ICs and the D24V50F5 module — should be warm but not hot. If either TB6612FNG is too hot to touch, increase copper pour area under it.

**Test 2 — Repeated hard reversal**
Alternate `CMD 255 255 0` and `CMD -255 -255 0` every 2 seconds, 20 times. Watch for ESP32 resets or Pi undervoltage icon. This is the worst case for back-EMF transients and TB6612FNG thermal stress.

**Test 3 — Stall one wheel**
Block one wheel by hand for 3 seconds. Robot should not reset. Polyfuse should not trip (single motor stall is ~1.8A, well under 7A hold current). Release and confirm motors spin up correctly.

**Test 4 — Full system under inference**
Run full YOLO stack on Pi while robot follows. Watch Pi temperature (vcgencmd measure_temp). Target under 70C with heatsink. If throttling occurs (check with vcgencmd get_throttled), add a 30mm fan. -- (UPDATE: this test wasd one Pi's average temp was 61C)

---
## Initial Test Results

| Test | Result |
|---|---|
| Full throttle | PENDING, voltage drop measured at ___V |
| Hard reversal | PENDING, no ESP32 resets |
| Single motor stall | PENDING |
| YOLO inference | Temp averaged with 61C with active cooler running YOLO and media. |

Measurement method for yolo interface: 
- vcgencmd measure_temp
- YOLOv8 pose inference active
- media playback active
- arduino with OLED, MPU6050, and ultrasonic sensor active. 

## Failure Mode Analysis(FMEA)

### 1. Motor Burn from Sustained Stall
**Cause:** Wheel jammed, motor at stall current (~1.5-2.2A at 7.4V).
**Mitigation:** The ESP32 watchdog stops the motors if commands stop arriving from the Pi for 500ms. This protects against cases where the Pi crashes or communication is interrupted.

### 2. RPi Brownout from 5V Sag
**Cause:** Pi current spike faster than buck converter response.
**Mitigation:** D24V50F5 (5A rated, ~0.5A headroom at Pi 5 peak) + 1000uF output cap. The output capacitor helps handle short current spikes before the buck converter can react

### 3. Ghost Resets from Ground Bounce
**Cause:** Motor switching current through shared ground traces injects noise into ESP32 GND reference.
**Mitigation:** Full ground plane on bottom PCB layer, stitching vias. 470uF bulk caps at each TB6612FNG VM pin. Single star ground entry point at XT30 connector. This was added because motor currents are much larger than sensor currents. 

### 4. ESP32 GPIO Damage from HC-SR04 5V Echo
**Cause:** HC-SR04 echo output is 5V. ESP32 GPIO max input 3.6V.
**Mitigation:** 1k/2k voltage divider on every echo line. 

### 5. Battery Over-Discharge
**Cause:** 2S LiPo below 3.0V/cell (6.0V total) causes permanent cell damage and swelling.
**Mitigation:** Battery voltage sense circuit (10k/3.3k divider to ADC). Firmware cuts motors and flashes LED at 6.4V (3.2V/cell). Also saves the end of a test run. THe LED warning gives time to land gracefully :P.

### 6. Motor Wiring Polarity Error
**Cause:** Motor connector plugged backward. One side drives in reverse. Robot spins in circles 👎.
**Mitigation:** Polarity marked on PCB silkscreen. Test each motor independently with `CMD 100 100 0` before full assembly.

### 7. I2C Bus Lockup
**Cause:** if coms is interrupted while the MPU-6050 is sending data it can leave SDA stuck low and cause other I2C devices from working. 
**Mitigation:** I2C bus recovery routine in firmware init (9 SCL clocks while SDA high). Runs before main loop.

### 8. UART Garbage on Pi Boot
**Cause:** Pi kernel uses GPIO14 (UART TX) for boot messages. Arrives at ESP32 as garbage bytes.
**Mitigation:** Firmware discards any line that does not start with the `CMD` prefix. Also: disable serial console in raspi-config on Pi setup (required step, see vision README).

### 9. PWM Noise on Encoder/Sensor Lines
**Cause:** 20kHz PWM couples capacitively into parallel sensor wires. Adds noise to encoder counts and HC-SR04 echo timing.
**Mitigation:** 100nF cap on each encoder signal line to GND at ESP32 pin. Route sensor cables away from motor cables. Keep ultrasonic cables under 20cm.

### 10. Pi Thermal Throttling Under Inference
**Cause:** Pi 5 SoC reaches 85C without cooling. Throttles from 2.4GHz down. Drops YOLO FPS. Slows following response.
**Mitigation:** Active cooler already installed on Pi 5 (from friend). 

### 11. HC-SR04 Simultaneous Firing (Crosstalk)
**Cause:** All three sensors fired at the same time. Sensor B hears Sensor A's pulse as a phantom reflection at ~0 cm. ESP32 registers a phantom wall directly in front and triggers the escape sequence every cycle.
**Mitigation:** Sequential sensor firing with 60ms minimum delay between each sensor. 

### 12. TB6612FNG Overheating with JGA25-370
**Cause:** JGA25-370 stall current (1.5-2.2A at 7.4V) exceeds TB6612FNG continuous rating (1.2A). Sustained near-stall conditions cause IC to overheat.
**Mitigation:** Exposed thermal pad on TB6612FNG QFN package must be connected to GND copper pour in KiCad footprint. Firmware soft-start (PWM ramp over 200ms) Run Test 2 and confirm ICs are warm and NOT toasty.

### 13. Control Loop Oscillation
**Cause:** 200ms vision-to-motor latency combined with aggressive turn commands. Robot overshoots center, camera now sees person on opposite side, sends opposite turn command, overshoots again. Robot sways left-right following person.
**Mitigation:** Exponential moving average on offset value in Pi code (0.7 x previous + 0.3 x new). Dead zone ±0.15 already helps but is not sufficient alone. See vision README for implementation.

### 14. Pi/ESP32 State Desync
**Cause:** Pi sends STOP (enters WAITING state). ESP32 is mid-execution of last forward command. 100-300ms of "ghost motion" occurs — robot moves when it should be stopped.
**Mitigation:** Pi flushes serial write buffer before entering WAITING state. ESP32 watchdog at 500ms handles the case where Pi goes silent entirely.

### 15. Ultrasonic Sensor Dropout Cascade
**Cause:** HC-SR04 returns no echo (object too close, sensor disconnected, electrical noise). Firmware interprets timeout as either 0cm (triggers escape loop constantly) or max range (treats path as clear when it is not).
**Mitigation:** Readings outside 2-400cm range flagged as INVALID. Firmware holds last known valid reading for up to 3 cycles (540ms) before reverting to safe default (treat as obstacle at 20cm). See firmware README.

---
## Future Testing. 
Planned:
- [ ] Complete motor stress testing after PCB assembly
- [ ] Measure actual battery runtime
- [ ] Validate thermal performance under continuous following
- [ ] Tune obstacle avoidance parameters
---

## PCB Design Checklist

**Schematic (COMPLETE — 0 ERC errors, all footprints assigned):**
- [x] ESP32-WROOM-32 with 100nF + 10uF decoupling on VCC
- [x] TB6612FNG x2 (U6, U7) — all control pins connected, STBY tied HIGH
- [x] 470uF bulk cap at each TB6612FNG VM pin (2 caps total)
- [x] AMS1117-3.3 (U5) with 10uF + 100nF on input and output
- [x] D24V50F5 (5V/5A) module placed via J8; VIN←VBAT, VOUT→+5V; 1000uF + 100nF output caps
- [x] Reverse polarity MOSFET Q2 (AOD4185 P-channel) on VBAT input
- [x] 7A-rated polyfuse F2 (Littelfuse RGEF700) on VBAT line
- [x] AMS1117-3.3 input connected to 5V rail (D24V50F5 output) — NOT to VBAT
- [x] 1k/2k voltage dividers on all 3 HC-SR04 Echo lines (6 resistors)
- [x] 4.7k I2C pull-ups on SDA and SCL to 3.3V
- [x] Battery voltage sense divider (10k + 3.3k) to ESP32 ADC pin (GPIO36)
- [x] Boot button SW2 (GPIO0 to GND)
- [x] Reset button SW1 (EN to GND with 10k pull-up)
- [x] Status LED D1 with 100Ω current limiting resistor R11
- [x] Test points TP1–TP6 on VBAT, +5V, +3V3, GND, ESP_TX, ESP_RX
- [x] Encoder connectors J13 (ENC_L) and J14 (ENC_R)
- [x] ERC clean — 0 errors

**Layout (COMPLETE — DRC clean, Gerbers exported):**
- [X] Ground plane poured on bottom copper layer, net = GND
- [X] Stitching vias every 10mm across board area
- [X] Single star ground entry at XT30 negative terminal
- [X] TB6612FNG exposed thermal pad connected to GND copper pour (NOT floating) — verify in KiCad footprint properties
- [X] D24V50F5 module footprint matches Pololu pin layout; GND pads to ground pour
- [X] 470uF bulk caps within 3mm of each TB6612FNG VM pin
- [X] 1000uF cap within 5mm of D24V50F5 output pin
- [X] All 100nF decoupling caps within 2mm of IC power pins
- [X] TB6612FNG placed adjacent to motor output connectors
- [X] Motor output traces >= 1.2mm
- [X] VBAT traces >= 2.5mm
- [X] 5V RPi traces >= 1.5mm
- [X] Encoder traces routed away from motor traces (opposite PCB side preferred)
- [X] Polarity marked on motor connectors in silkscreen
- [X] Board outline matches dimensions given to mechanical team
- [x] DRC clean — zero errors
- [x] Gerbers exported and verified in viewer

---

## Timeline

| Week | Target | Status |
|---|---|---|
| 1-2 | Schematic complete — all blocks, all decoupling, all connectors, ERC clean | **DONE** |
| 2-3 | PCB layout with ground plane, DRC clean, Gerbers exported | **DONE** |
| 3 | Gerbers to JLCPCB, 5 boards ordered | Next |
| 4-5 | PCB arrives, solder, power-on test | — |
| 5 | Run electrical stress test protocol before connecting Pi | — |

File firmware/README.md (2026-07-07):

# Firmware — Philo ESP32

**Owner: [@dish-glitch](https://github.com/dish-glitch)**

---

## Overview

The ESP32 firmware handles everything physical — spinning motors, reading encoders, polling ultrasonic sensors, and listening for commands from the Raspberry Pi. It does not register people or cameras. It just moves the bot and avoids walls.

Built with PlatformIO. Framework: Arduino (easier to use as we already one which saved us from needing to acquire an ESP-IDF).

---

## Responsibilities

| Task | How | Status |
|---|---|---|
| Receive direction + speed commands | UART from Raspberry Pi at 115200 baud, non-blocking line parser | ✅ implemented |
| Drive motors | PWM via ESP32 LEDC peripheral, 20kHz frequency | ✅ implemented |
| Send telemetry to Pi | `STATUS` line at 10 Hz (vbat, distances, encoders, IMU) | ✅ implemented |
| Watchdog | Stop motors if no CMD received in 500ms | ✅ implemented — `apply_drive()` runs every loop pass |
| Read ultrasonic sensors | One sensor per 60ms slot, round-robin (40kHz crosstalk guard), invalid-reading holdoff | ✅ implemented |
| Override Pi commands on obstacle | Center < 25cm → stop; side < 30cm → veer away | ✅ implemented — needs on-robot tuning |
| Detect tip-over | Gravity-vector tilt from MPU-6050; cut motors above 30° | ✅ implemented — clears when righted |
| Boot-time UART flush + I2C bus recovery | Discard stale serial bytes; 9-clock SCL release before `Wire.begin` | ✅ implemented |
| ASL letter display | `ASL <letter>` line → big letter on OLED for 2s | ✅ implemented |
| Control speed closed-loop | PID per motor side using encoder pulse counting | ⬜ next — encoders count, PID loop lands after motors verified on PCB |

> **Status note:** everything above compiles and the safety chain
> (tilt > watchdog > brake/coast > obstacle > Pi command) is in `main.cpp`, but none
> of it has run on the real PCB yet. Thresholds (25cm/30cm/30°/500ms) will need
> tuning during hardware bring-up.

---

## Serial Protocol (UART — Raspberry Pi to ESP32)

**Baud rate:** 115200
**Format:** `CMD <left> <right> <flags>\n` — **numeric differential drive** (as implemented in [`src/pi_comm.cpp`](src/pi_comm.cpp))

| Field | Range | Meaning |
|---|---|---|
| `left` | -255..255 | left-side wheel speed (negative = reverse, 0 = coast) |
| `right` | -255..255 | right-side wheel speed |
| `flags` | bitfield | bit 0 = coast stop, bit 1 = hard brake, 0 = normal drive |

Independent left/right speeds let the Pi steer **proportionally** (curve smoothly toward the person) instead of issuing discrete F/B/L/R/S turns. `motor_set(left, right)` in [`src/motors.h`](src/motors.h) drives the two sides directly.

**Examples:**
```
CMD 180 180 0\n   -> straight ahead at ~70% speed
CMD 180 110 0\n   -> curve right (right wheels slower)
CMD 0 0 1\n       -> stop (coast)
CMD 0 0 2\n       -> stop (hard brake)
```

The ESP32 parses each line as it arrives. If a line is malformed or (once implemented) the watchdog timer expires (no command for 500ms), motors stop immediately.

> **Historical note:** earlier drafts of this doc used a `CMD:<direction>,<speed>` format (`CMD:F,180`). That was replaced by the numeric differential-drive format above, which is what the firmware and the Pi-side code actually implement.

---

## Motor Control

**4 motors, 4 channels, 2 chips, controlled as 2 sides:**
- Each motor has its OWN H-bridge channel (left-front, left-rear, right-front, right-rear = 4 channels across 2 TB6612FNG chips). Do NOT parallel two motors onto one channel — two JGA25-370s stall at 3-4.4A combined, over the TB6612FNG 3.2A peak rating.
- The two left motors share the same control signals (PWM_L/IN1/IN2 on GPIO 25/26/27), so they always move identically. The two right motors share the same control signals (GPIO 32/33/14). Electrically separate channels, logically one "side." See [hardware SCHEMATIC.md](../hardware/SCHEMATIC.md) Sheet 3 for the exact fan-out.

**PWM:** ESP32 LEDC peripheral, 20kHz. Human ears hear up to ~20kHz — running PWM at exactly 20kHz puts motor whine right at the edge of hearing. In practice it is nearly silent compared to lower frequencies.

**PID speed control per side:**
Encoders count pulses per unit time. The PID loop compares actual speed (encoder pulses/sec) to the target speed from the Pi command, and adjusts PWM duty cycle to close the gap.

```
error = target_speed - measured_speed
output = Kp * error + Ki * integral + Kd * derivative
clamp output to 0-255
write to PWM
```

Tune Kp first (increase until robot responds without oscillating), then Ki (removes steady-state error), Kd last (dampens overshoot). Start with Kp=1.0, Ki=0.1, Kd=0.05 and adjust from there.

Each side has its own PID instance. This is what keeps the robot driving straight instead of drifting — if one motor is slightly faster than the other, the PID corrects it automatically.

**Soft-start — required to protect TB6612FNG:**

On every new movement command (transitioning from stop to motion), ramp PWM from 0 to the target duty cycle over 200ms. Do not jump immediately to full duty cycle.

```cpp
void soft_start(uint8_t target_pwm, uint8_t motor_side) {
    uint8_t current = 0;
    while (current < target_pwm) {
        current = min(current + 5, target_pwm);
        set_motor_pwm(motor_side, current);
        delay(10);  // 200ms total for 0->255 ramp, shorter for lower targets
    }
}
```

Why: JGA25-370 motors starting from rest on carpet are near stall for 100-400ms. Without soft-start, TB6612FNG sees repeated stall-current bursts on every start. With soft-start, the current rises gradually as the motor accelerates, never hitting peak stall.

---

## Ultrasonic Sensor Logic

Three HC-SR04 sensors: front-left, front-center, front-right.

### CRITICAL: Fire sensors sequentially, never simultaneously

**DO NOT fire all three HC-SR04 sensors at the same time.** If multiple sensors fire simultaneously, each sensor may pick up the ultrasonic pulse from another sensor rather than its own reflection. This causes false short-range readings (phantom walls) that trigger the obstacle escape sequence repeatedly.

**Confirmed failure mode:** Sensor A fires a 40kHz pulse, Sensor B fires at the same time, Sensor B's echo pin goes high from Sensor A's pulse (wrong reflection), ESP32 reads 0.03m where there is no object.

**Fix: 60ms gap between each sensor fire.** Total scan cycle is 180ms for all three sensors.

```
Timing:
  t=0ms:    Fire front-center trigger
  t=60ms:   Read front-center echo, fire front-left trigger
  t=120ms:  Read front-left echo, fire front-right trigger
  t=180ms:  Read front-right echo — cycle complete, restart
```

**Reading one sensor:**
```
1. Pull trigger pin HIGH for 10 microseconds
2. Pull trigger pin LOW
3. Wait for echo pin to go HIGH (timeout 30ms if nothing detected)
4. Measure how long echo pin stays HIGH
5. distance_cm = echo_duration_us / 58.0
```

**Sensor invalid reading handling:**

HC-SR04 can return no echo (object too close, noise, wiring fault). Do not interpret timeout as 0cm (triggers escape loop) or as max range (treats blocked path as clear). Instead:

```cpp
#define SENSOR_MIN_CM 2
#define SENSOR_MAX_CM 400
#define SENSOR_INVALID_HOLDOFF_CYCLES 3

uint16_t last_valid[3] = {400, 400, 400};  // default to far/clear
uint8_t  invalid_count[3] = {0, 0, 0};

void update_sensor(int idx, uint16_t raw_cm) {
    if (raw_cm < SENSOR_MIN_CM || raw_cm > SENSOR_MAX_CM) {
        invalid_count[idx]++;
        if (invalid_count[idx] >= SENSOR_INVALID_HOLDOFF_CYCLES) {
            last_valid[idx] = 20;  // treat as obstacle after 3 bad readings
        }
        // else: hold last known valid reading
    } else {
        last_valid[idx] = raw_cm;
        invalid_count[idx] = 0;
    }
}
```

Use `last_valid[idx]` in the priority logic below, never raw readings.

**Priority override (runs before applying Pi command, implemented in `main.cpp` `apply_drive()`):**
```
if front_center < 25cm and moving forward:
    stop (hold until path clears — Pi keeps sending commands, override wins)
elif front_left < 30cm:
    slow the RIGHT side to 60% → robot veers right, away from the obstacle
elif front_right < 30cm:
    slow the LEFT side to 60% → robot veers left, away from the obstacle
else:
    apply Pi command normally
```

A differential-drive robot turns toward its **slower** side — so to veer away from
an obstacle you slow the side **opposite** it. (An earlier draft of this pseudo-code
had the sides swapped, which would have steered into the obstacle.) Reverse commands
bypass the obstacle check so the robot can always back away. The back-up-and-spin
escape sequence is a possible upgrade once the simple stop is proven on hardware.

**Ultrasonic side blind spots:** The HC-SR04 has a ~15 degree cone angle. Objects that approach from a 45-75 degree angle (between the sensor cones) may not be detected until very close. The angled sensor placement mitigates this but does not eliminate it. Do not position the robot such that furniture is approaching from the sides — the sensors only protect the front.

---

## Gesture Control Response

The gesture detection runs entirely on the Raspberry Pi (see vision README). The ESP32 does not know what a gesture is. When the Pi detects a raised hand, it sends `CMD 0 0 1\n` (coast stop). When the hand is lowered, it resumes sending normal drive commands.

The ESP32 just follows orders. The watchdog timer is important here — if the Pi is in WAITING state and sends nothing, the ESP32 must not keep driving from the last command. Set watchdog to 500ms: if no command arrives within 500ms, stop motors.

---

## IMU — Tip-Over Detection

MPU-6050 over I2C. Read pitch angle every 100ms. If pitch exceeds +/-30 degrees (robot tipping forward or backward), cut all motor power immediately and hold until pitch returns to safe range.

This protects the PCB and camera if the robot drives off a ledge or tips on a ramp.

**UART buffer flush on boot:**

When ESP32 resets (power cycle or watchdog), the Pi's serial write buffer may contain queued commands from before the reset. On boot, flush the UART receive buffer before entering the main loop — discard everything in the buffer accumulated while ESP32 was offline:

```cpp
void setup() {
    Serial2.begin(115200, SERIAL_8N1, RX_PIN, TX_PIN);
    delay(300);  // wait for Pi to potentially send stale data
    while (Serial2.available()) Serial2.read();  // flush
    i2c_bus_recovery();
    // ... rest of setup
}
```

Without this, the robot may execute stale commands (e.g., `CMD 255 255 0` from before the crash) immediately on recovery.

**I2C bus recovery:** Run a 9-clock SCL recovery routine at firmware init before starting the main loop. This clears any stuck-SDA-low condition left over from a hard reset or Pi reboot mid-transaction:

```cpp
// I2C bus recovery — 9 SCL clocks with SDA high
void i2c_bus_recovery() {
    for (int i = 0; i < 9; i++) {
        digitalWrite(SCL_PIN, HIGH);
        delayMicroseconds(5);
        digitalWrite(SCL_PIN, LOW);
        delayMicroseconds(5);
    }
}
```

---

## Companion Display — OLED Eyes  — ⚠️ PLANNED

> **Status:** Not implemented yet. The current [`display.cpp`](src/display.cpp) drives **one** SSD1306 as a **telemetry readout** (`display_status()` shows battery, ultrasonic distances, encoder counts). The animated dual-eye / mood system below — including the `MOOD:` UART extension — is the design target. Build it on top of the current display module; until then the Pi should not depend on `MOOD:` packets being understood.

Philo is a companion robot, so the goal is to give it a face: two SSD1306 OLED displays (128x64, I2C) acting as animated eyes. The ESP32 drives them because it is already the I2C master and it knows the robot's real-time state (moving, stopped, obstacle, tilt, low battery).

**Hardware:** Two OLEDs on the existing I2C bus, at addresses 0x3C and 0x3D (set by the address-select jumper/resistor on each module). The MPU-6050 is already on this bus at 0x68, so the bus now carries three devices. The existing 4.7k pull-ups are adequate for three devices on a short bus.

### CRITICAL: Run the display on core 1, not in the control loop

A full 128x64 OLED refresh over I2C at 400kHz takes ~23ms. Two displays is ~46ms. If you render eyes inside the main control loop, you destroy PID timing and the robot drives badly.

The ESP32 is dual-core. Pin the display rendering to **core 1** as a separate FreeRTOS task. The control loop (motors, PID, sensors, UART, watchdog) stays on **core 0** where it runs uninterrupted.

```cpp
// Shared state — written by core 0, read by core 1
volatile RobotMood current_mood = MOOD_NEUTRAL;

void display_task(void *param) {
    init_oled(0x3C);  // left eye
    init_oled(0x3D);  // right eye
    for (;;) {
        render_eyes(current_mood);   // draw both eyes for current mood
        vTaskDelay(pdMS_TO_TICKS(100));  // ~10 FPS, plenty for eye animation
    }
}

void setup() {
    // ... control setup on core 0 ...
    xTaskCreatePinnedToCore(display_task, "eyes", 4096, NULL, 1, NULL, 1);  // core 1
}
```

Eye rendering reads `current_mood` but never writes shared control state. Core 0 sets the mood flag; core 1 just draws. No mutex needed for a single volatile enum.

### Mood states

The ESP32 derives most expressions from its own state. The Pi sends optional hints for vision-driven moods over UART.

| Mood | Trigger (who sets it) | Eye expression |
|---|---|---|
| NEUTRAL | Following normally (core 0) | Open, looking forward |
| HAPPY | Pi sends `MOOD:FOUND` when target acquired | Curved/smiling eyes |
| SEARCHING | Pi sends `MOOD:LOST` when no person detected | Eyes glance side to side |
| WAITING | Pi sends `MOOD:WAIT` on raised-hand gesture | Half-closed, calm |
| ALERT | Obstacle detected by ultrasonic (core 0) | Wide eyes |
| DIZZY | IMU tilt > 30 degrees (core 0) | Spiral / X eyes |
| SLEEPY | Low battery < 6.4V (core 0) | Drooping eyes |

### MOOD protocol extension

When implemented, the Pi will send mood hints over the existing UART link using a second command prefix, parsed alongside `CMD`:

```
MOOD:FOUND\n     -> set current_mood = HAPPY
MOOD:LOST\n      -> set current_mood = SEARCHING
MOOD:WAIT\n      -> set current_mood = WAITING
```

`MOOD:` packets only set the display flag — they never move motors. State set by core 0 (ALERT, DIZZY, SLEEPY) takes priority over Pi mood hints, because safety-relevant state should always show on the face.

---

## Firmware Structure (PlatformIO)

```
firmware/esp32/
+-- platformio.ini          # board = esp32dev, framework = arduino
+-- src/
|   +-- main.cpp            # setup() and loop()
|   +-- motors.cpp / .h     # PWM, PID, encoder ISR
|   +-- ultrasonic.cpp / .h # HC-SR04 sequential polling and priority logic
|   +-- imu.cpp / .h        # MPU-6050 I2C read, tilt check
|   +-- pi_comm.cpp / .h    # UART parse (CMD numeric), STATUS send; MOOD parse planned
|   +-- display.cpp / .h    # OLED eyes, core-1 FreeRTOS task, mood rendering
+-- test/                   # unit tests if needed
```

---

## Pin Assignment (final — verified from KiCad netlist)

| Function | ESP32 GPIO | Notes |
|---|---|---|
| Left motor PWM | GPIO 25 | LEDC channel |
| Left motor direction A | GPIO 26 | TB6612FNG AIN1 |
| Left motor direction B | GPIO 27 | TB6612FNG AIN2 |
| Right motor PWM | GPIO 32 | LEDC channel |
| Right motor direction A | GPIO 33 | TB6612FNG BIN1 |
| Right motor direction B | GPIO 14 | TB6612FNG BIN2 |
| Left encoder | GPIO 34 | Input-only pin |
| Right encoder | GPIO 35 | Input-only pin |
| Ultrasonic front-center trigger | GPIO 5 | |
| Ultrasonic front-center echo | GPIO 18 | After 1k/2k voltage divider |
| Ultrasonic front-left trigger | GPIO 19 | |
| Ultrasonic front-left echo | GPIO 4 | After 1k/2k voltage divider |
| Ultrasonic front-right trigger | GPIO 13 | |
| Ultrasonic front-right echo | GPIO 23 | After 1k/2k voltage divider |
| IMU SDA | GPIO 21 | I2C with 4.7k pull-up to 3.3V |
| IMU SCL | GPIO 22 | I2C with 4.7k pull-up to 3.3V |
| UART RX (from Pi TX) | GPIO 16 | |
| UART TX (to Pi RX) | GPIO 17 | |
| Battery ADC | GPIO 36 | Input-only, 10k/3.3k divider |
| Status LED | GPIO 2 | 100 ohm series resistor |

*Pin assignments are final — verified from KiCad netlist. Do not change without updating both the schematic and this table.*

*Previous revision had a conflict: GPIO 21 was assigned to both ultrasonic front-left echo AND I2C SDA, and GPIO 22 was assigned to both front-right trigger AND I2C SCL. This table resolves both conflicts. Ultrasonic echo uses GPIO 4/18/23; ultrasonic triggers use GPIO 5/13/19; I2C uses GPIO 21/22 as intended.*

---

## Timeline

| Status | Milestone |
|---|---|
| **DONE** | All firmware modules compile — motors, encoders, ultrasonic, IMU, OLED, Pi UART |
| **DONE** | UART command parsing — robot responds to `CMD <left> <right> <flags>` |
| **DONE** | Gesture stop tested on Arduino stand-in |
| **DONE** | ASL letter display over UART tested on Arduino stand-in |
| **DONE** | Safety layer in ESP32 firmware — 500ms watchdog, obstacle override, tilt cutoff, sequential ultrasonic firing (60ms slots), UART boot flush, I2C bus recovery, `ASL` display handler |
| Next | PCB arrives — verify all modules + safety thresholds on real ESP32 hardware |
| Next | Encoders reading, PID loop running, robot drives straight |
| Next | IMU tilt threshold tuning, full integration with Pi |
| Next | PID tuning, edge cases, demo readiness |

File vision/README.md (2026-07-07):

# Vision — Philo Raspberry Pi Stack

**Owner: [@sivathamizhan](https://github.com/sivathamizhan) & [@dish-glitch](https://github.com/dish-glitch)**

---

## Overview

The Raspberry Pi 5 is Philo's eyes and brain. It runs a camera feed through YOLOv8 pose estimation, figures out where the person is relative to the robot's center, and sends short commands over serial to the ESP32 telling it which way to go.

It also handles gesture control entirely in software — no extra hardware needed. When the person raises their hand, the Pi detects it and sends a stop command. When they lower it, normal following resumes.

---

## Serial Protocol (matches the ESP32 firmware)

> **Source of truth:** [`firmware/esp32/src/pi_comm.cpp`](../firmware/esp32/src/pi_comm.cpp). The Pi sends **numeric differential-drive** commands — independent left/right wheel speeds — not direction codes. Independent wheel speeds give smooth proportional turning that discrete `F/L/R/S` codes cannot.

**Pi → ESP32:**
```
CMD <left> <right> <flags>\n
```
- `left`, `right` — wheel speeds, **-255..255** (negative = reverse, 0 = coast)
- `flags` — bit 0 = coast stop, bit 1 = hard brake (0 = normal drive)

**ESP32 → Pi (telemetry at 10 Hz):**
```
STATUS <vbat> <dl> <dc> <dr> <el> <er> <ax> <ay> <az> <gz>\n
```

Examples:
```
CMD 150 150 0     # straight ahead, ~60% speed
CMD 150 90 0      # gentle right (right wheels slower)
CMD 0 0 1         # stop (coast)
```

A working implementation of this protocol lives in [`vision/rpi/uart.py`](rpi/uart.py) and [`vision/rpi/controller.py`](rpi/controller.py).

---

## Camera Installation Requirements

**This must be done before any software development. If the camera is in the wrong physical position, gesture detection will not work regardless of how the code is written.**

### Why camera height matters

At a camera height of 200mm (robot body), the camera mounted level sees a 1.7m person from ~40mm to ~720mm height at 1.5m distance — only legs. Raising a hand is invisible.

At 380mm height with 25 degree upward tilt:
```
Camera at 380mm, tilted 25 degrees up, person 1.5m away:
  Bottom of frame: 380 + 1500 x tan(0.6 degrees) = ~396mm (knee height)
  Center of frame: 380 + 1500 x tan(25 degrees) = ~1079mm (mid-torso)
  Top of frame:    380 + 1500 x tan(49.4 degrees) = ~2130mm (above head)
```

The camera sees from knee height to above the head. Wrists and shoulders are clearly visible. Gesture detection works.

### Camera mounting specification (give this to hummos430)

- Camera height from ground: **380mm** (requires a ~200mm mast above the chassis body)
- Camera tilt: **20-25 degrees upward** from horizontal
- Mast minimum cross-section: 20mm x 20mm PETG-CF (to prevent flex during movement)
- CSI ribbon cable must be strain-relieved within 20mm of both connectors

### Effect on steering logic

The tilt is vertical only. The horizontal left-right position mapping is unchanged — the offset calculation still works exactly as documented below. Vertical tilt does not affect the horizontal plane.

---

## Setup (Do This First)

1. Flash Raspberry Pi OS Lite 64-bit to SD card (use Raspberry Pi Imager)
2. Enable camera interface: `sudo raspi-config` -> Interface Options -> Camera
3. **Disable serial console** (required — Pi sends boot messages over UART which corrupt ESP32 commands):
   `sudo raspi-config` -> Interface Options -> Serial Port -> Shell: No, Hardware: Yes
4. Confirm camera works: `libcamera-hello --timeout 5000`
5. Install dependencies:

```bash
pip install ultralytics opencv-python pyserial picamera2
```

6. Download the model (first run downloads automatically, or manually):

```bash
python -c "from ultralytics import YOLO; YOLO('yolov8n-pose.pt')"
```

---

## Camera Configuration (Exposure Lock)

**Run this at startup before the inference loop. Do not skip it.**

When the robot moves from a bright window to a dim hallway, auto-exposure takes 10-20 frames to adjust. During those frames, YOLO receives washed-out or underexposed images and detection fails — the robot stops following and loses the person.

Fix: let the camera auto-expose for 30 frames on startup, then lock the settings for the session.

```python
from picamera2 import Picamera2

picam2 = Picamera2()
config = picam2.create_video_configuration(main={"size": (640, 480)})
picam2.configure(config)
picam2.start()

# Let auto-exposure stabilize
for _ in range(30):
    frame = picam2.capture_array()

# Lock exposure settings
picam2.set_controls({
    "AeEnable": False,          # disable auto-exposure
    "AwbEnable": False,         # disable auto white balance
    "ExposureTime": picam2.capture_metadata()["ExposureTime"],
    "AnalogueGain": picam2.capture_metadata()["AnalogueGain"],
    "ColourGains": picam2.capture_metadata()["ColourGains"],
})
```

**Trade-off:** locked exposure means the image will get brighter or darker if room lighting changes. For a living room demo under consistent indoor lighting this is fine. If the robot will operate in dramatically varying light (e.g., outside), do not lock exposure — accept the 10-20 frame detection gap instead.

---

## Model Choice

**yolov8n-pose.pt** — YOLOv8 nano pose estimation model.

- Detects people AND their 17 body keypoints in a single pass
- Runs at 15-20 FPS on Raspberry Pi 5 at imgsz=320
- This is fast enough for following a walking person
- Do not use the larger models (s, m, l) — they are too slow on Pi hardware without a GPU

The 17 keypoints follow the COCO standard. The ones Philo uses:

| Index | Keypoint |
|---|---|
| 5 | Left shoulder |
| 6 | Right shoulder |
| 9 | Left wrist |
| 10 | Right wrist |

---

## Person Following Logic

Every frame:

1. Run YOLOv8n-pose inference on the camera frame
2. Select the target person (see Person Selection below)
3. Get their bounding box center X position
4. Calculate offset from frame center (smoothed):

```python
# Exponential moving average prevents jitter from single-frame keypoint noise
smoothed_offset = 0.0  # initialize at module level

def get_smoothed_offset(box_center_x, frame_width):
    global smoothed_offset
    raw_offset = (box_center_x - frame_width / 2) / (frame_width / 2)
    smoothed_offset = 0.7 * smoothed_offset + 0.3 * raw_offset
    return smoothed_offset

offset = get_smoothed_offset(box_center_x, frame_width)
# offset range: -1.0 (person far left) to +1.0 (person far right)
# offset near 0.0 = person is centered = go straight
```

Why: At 200ms control loop latency, a single noisy frame that puts the offset at +0.4 sends a hard right command. The robot turns, camera sees person now to the left, sends hard left command — system oscillates. The EMA (alpha=0.3) means a single bad frame contributes only 30% of the new value, dampening transient noise without adding lag to real tracking.

5. Estimate distance using bounding box height (smoothed):

```python
# Use a rolling average — raw bbox height is noisy (posture changes, camera shake)
from collections import deque
bbox_height_history = deque(maxlen=5)

def get_smoothed_height_ratio(box_height, frame_height):
    bbox_height_history.append(box_height / frame_height)
    return sum(bbox_height_history) / len(bbox_height_history)

box_height_ratio = get_smoothed_height_ratio(box_height, frame_height)
# ratio > 0.7 = person very close = slow down or stop
# ratio < 0.2 = person far away = speed up
# ratio 0.3-0.5 = comfortable following distance = normal speed
```

Why: A person bending over, turning sideways, or moving their arms changes the bounding box height by 10-30% in a single frame. Without smoothing, the system misreads this as a distance change and sends spurious speed commands — robot oscillates forward and backward.

6. Translate offset and distance into a command:

```python
DEAD_ZONE = 0.15  # ignore small offsets, prevents jitter

if box_height_ratio > 0.7:
    command = "CMD 0 0 1"                              # too close -> coast stop
else:
    speed = map_distance_to_speed(box_height_ratio)   # 0..255
    if offset > DEAD_ZONE:                            # person right -> slow right wheels
        left, right = speed, int(speed * (1 - offset))
    elif offset < -DEAD_ZONE:                         # person left -> slow left wheels
        left, right = int(speed * (1 + offset)), speed
    else:                                             # centered -> straight
        left, right = speed, speed
    command = f"CMD {left} {right} 0"
```

Steering is **proportional**: the further off-center the person is, the more one
side slows down, so the robot curves smoothly toward them instead of jerking with
fixed-rate turns. This is exactly what [`controller.py`](rpi/controller.py) does.

7. Send command over serial to ESP32

---

## Person Selection — Handling Multiple People in Frame

YOLOv8 detects every person visible. If a family member walks through the room, Philo might switch from following you to following them.

**V1 approach: follow the largest bounding box (closest person)**

The person who gave the robot its last gesture command is almost certainly the closest person in the frame. Follow whichever detection has the largest bounding box area.

```python
results = model(frame)
if results[0].boxes:
    boxes = results[0].boxes
    areas = boxes.xywh[:, 2] * boxes.xywh[:, 3]  # width x height
    target_idx = areas.argmax().item()
    # use boxes[target_idx] and keypoints[target_idx]
```

**Known limitation:** This is not true re-identification. If two people are at similar distances and one passes in front of the other, the robot may switch targets briefly. This is a known unsolved problem in person-following robotics. For a demo, it is acceptable. If needed, a future improvement would be to lock onto the person's approximate shirt color as a secondary identifier.

---

## Gesture Control Logic

**Condition for raised hand:**
In image coordinates, Y=0 is the TOP of the frame and increases downward. So a wrist that is physically above the shoulder will have a LOWER Y value in the image.

```python
def hand_raised(keypoints):
    left_wrist_y    = keypoints[9][1]
    left_shoulder_y = keypoints[5][1]
    right_wrist_y   = keypoints[10][1]
    right_shoulder_y = keypoints[6][1]

    # Only trust keypoints with confidence > 0.5
    left_wrist_conf  = keypoints[9][2]
    right_wrist_conf = keypoints[10][2]

    left_raised  = (left_wrist_y < left_shoulder_y) and (left_wrist_conf > 0.5)
    right_raised = (right_wrist_y < right_shoulder_y) and (right_wrist_conf > 0.5)

    return left_raised or right_raised
```

**State machine — prevents flickering:**

Do not switch state on a single frame. Require 5 consecutive frames of the same gesture before changing state.

```python
state = "FOLLOWING"
raised_frames  = 0
lowered_frames = 0
THRESHOLD = 5

# Inside the loop:
if hand_raised(keypoints):
    raised_frames  += 1
    lowered_frames  = 0
else:
    lowered_frames += 1
    raised_frames   = 0

if raised_frames  >= THRESHOLD:
    state = "WAITING"
if lowered_frames >= THRESHOLD:
    state = "FOLLOWING"

if raised_frames >= THRESHOLD and state != "WAITING":
    state = "WAITING"
    ser.flush()          # flush write buffer before going silent
    send_serial("CMD 0 0 1")   # coast stop

if lowered_frames >= THRESHOLD and state != "FOLLOWING":
    state = "FOLLOWING"

if state == "WAITING":
    send_serial("CMD 0 0 1")   # coast stop
else:
    send_serial(follow_command)
```

**Why gesture detection requires the elevated camera:** Gesture is detected by comparing wrist Y-coordinate to shoulder Y-coordinate in the image. If the camera only sees legs (low mount, no tilt), neither wrist nor shoulder keypoints are in frame and all confidence scores are 0. The gesture check will never trigger. The camera mast is not optional.

> **Known issue:** The current one-hand trigger (either wrist above shoulder) is too sensitive — reaching for something or a natural arm swing can stop the robot. Tracked in [issue #2](https://github.com/dish-glitch/Philobot/issues/2). Proposed fix: require both wrists above both shoulders simultaneously, and extend the debounce window to 1.5 seconds.

---

## What Happens When No Person Is Detected

If no person is in frame:

```python
if no detections:
    send_serial("CMD 0 0 1")   # coast stop and wait
```

Do not keep sending the last movement command — that causes the robot to drive blind. Stop and wait for the person to re-enter frame.

**Optional improvement (week 7):** if person is lost, spin slowly in the last known direction for up to 2 seconds while searching. If not found, stop.

**Known limitation — occlusion:** If the person walks behind a wall or large piece of furniture and another person is standing nearby, Philo may start following the second person when the first reappears. There is no reliable fix for this within the V1 scope. The robot's behavior when it loses the target is to stop, which is safe. Accept this limitation and document it in the demo.

---

## Serial Output to ESP32

```python
import serial

ser = serial.Serial('/dev/ttyS0', 115200, timeout=1)
# On some Pi setups the port is /dev/ttyAMA0 — check with: ls /dev/tty*

def send_serial(command):
    ser.write((command + '\n').encode('utf-8'))
```

Send one command per inference loop iteration. Do not flood the serial port — one command per frame is enough.

---

## Companion Audio (Pi-side) and Eye Mood Hints

Philo is a companion robot. The Pi drives two things beyond following:

1. **Sound clips** — short WAV files for personality (the speaker is on the Pi, not the ESP32; see hardware README for why)
2. **Eye mood hints** — the OLED eyes are driven by the ESP32, but the Pi tells it which mood to show for vision-driven states (found you / lost you / waiting)

### Sound clips

Pre-recorded WAV files played on state changes. NOT live text-to-speech, NOT a ChatGPT voice pipeline — those are V2 (they would compete with YOLO for CPU and add internet dependency).

```python
import subprocess

def play_clip(name):
    # non-blocking — don't stall the inference loop waiting for audio
    subprocess.Popen(["aplay", f"/home/pi/philo/sounds/{name}.wav"],
                     stdout=subprocess.DEVNULL, stderr=subprocess.DEVNULL)

# Trigger on state TRANSITIONS only, not every frame:
#   target acquired after being lost -> play_clip("found")
#   person lost                      -> play_clip("searching")
#   raised-hand gesture detected     -> play_clip("waiting")
```

Only play a clip when the state actually changes. Playing a clip every frame produces a stutter of overlapping sounds. Gate on transition.

### Eye mood hints over UART  — ⚠️ PLANNED, not yet in firmware

> **Status:** The current ESP32 firmware ([`pi_comm.cpp`](../firmware/esp32/src/pi_comm.cpp)) only parses `CMD` lines, and [`display.cpp`](../firmware/esp32/src/display.cpp) shows a **telemetry readout** (battery/distances/encoders), not animated eyes. The `MOOD:` protocol and OLED-eyes below are a **design target**, not implemented yet — don't rely on them for integration until the firmware side lands. See [firmware README → Companion Display](../firmware/README.md).

When the vision state changes, the plan is to send a `MOOD:` packet to the ESP32 so the eyes match. It rides the existing serial link alongside `CMD` lines.

```python
def send_mood(mood):       # mood in {"FOUND", "LOST", "WAIT"}
    ser.write((f"MOOD:{mood}\n").encode('utf-8'))

# On transition into following with a target:
send_mood("FOUND")
# On losing the person:
send_mood("LOST")
# On raised-hand gesture (WAITING state):
send_mood("WAIT")
```

`MOOD:` packets do not affect motion — the ESP32 only uses them to pick an eye expression. Safety states (obstacle, tilt, low battery) are set by the ESP32 itself and override Pi mood hints.

---

## File Structure

Current files (implemented):
```
vision/rpi/
+-- main.py              # main loop -- camera, inference, following, gesture, ASL
+-- tracker.py          # YOLOv8 pose + object detection wrapper
+-- controller.py       # bbox -> CMD <left> <right> <flags> + gesture state machine
+-- uart.py             # serial link to ESP32 (CMD out, STATUS in)
+-- gamepad.py          # Xbox controller -> manual drive (--manual flag, A toggles AUTO)
+-- gamepad_test.py     # standalone controller axis/button mapping tester
+-- test_link.py        # serial link smoke test
+-- webcam_stream.py    # phone/laptop camera streaming helper
+-- asl_features.py     # canonical scale-invariant hand features (train + infer)
+-- asl_from_dataset.py # train ASL model from the Kaggle ASL Alphabet dataset
+-- asl_collect.py      # alt: collect your own ASL samples from webcam
+-- asl_run.py          # standalone ASL tester
```

Planned (companion features, not yet implemented):
```
+-- audio.py            # sound-clip playback (aplay) on state transitions
+-- sounds/             # found.wav, searching.wav, waiting.wav, etc.
```

> Note: the gesture state machine and following/distance smoothing described
> above are documented as standalone snippets here; in the current code they live
> inside `controller.py` and `main.py`. The EMA offset and rolling-height smoothing
> are good upgrades not yet folded into `controller.py` — see the issue tracker.

---

## Performance Targets

| Metric | Target |
|---|---|
| Inference FPS | 10+ FPS |
| Latency per frame | < 100ms |
| Minimum confidence to track | 0.5 |
| Dead zone | 0.1 (+/-10% of frame center, per `controller.py`) |
| Max comfortable follow distance | ~3 meters |

If FPS drops below 8, reduce input size: `model(frame, imgsz=224)` instead of 320.

---

## Timeline

| Week | Target |
|---|---|
| 1 | RPi OS flashed, camera confirmed with libcamera-hello, serial console disabled |
| 2-3 | YOLOv8n-pose running, person detected on test image |
| 4 | Camera mast installed, exposure lock confirmed working |
| 4-5 | Live inference from camera, offset values printing to terminal |
| 5-6 | Serial output to ESP32 working, robot responds to person position |
| 6 | Gesture control — raised hand stops robot |
| 7 | Tuning dead zone, distance thresholds, lost-person behavior |
| 8 | Stable enough for demo video |

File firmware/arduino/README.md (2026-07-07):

# Arduino Uno — bench-test firmware

Sketches used to develop and validate Philo on a breadboard before the real
ESP32 PCB exists. The Uno stands in for the ESP32.

## `arduino_philo.ino` — the ESP32 stand-in (receiver + safety layer)

Reads the laptop's serial protocol, drives the dashboard, and runs an obstacle
safety override on its own ultrasonic sensor, serving as the ESP32 while the PCB is unavailable.

- **`CMD <left> <right> <flags>`**
  - follow LED: D6 lights when moving, turns off when stopped
  - turn LEDs: D7 lights when steering left, D8 when steering right
  - OLED: shows `FOLLOW`/`STOPPED`/`OBSTACLE`, direction, and live distance
- **`ASL <LETTER>`** — flashes the big letter on the OLED for 2s
- **Obstacle override** — reads its own HC-SR04; if something is closer than
  `OBSTACLE_CM` (20cm), forces STOP regardless of the camera command. Safety
  does not depend on the laptop or the link staying alive.
- **Telemetry** — sends `STATUS <vbat> <dl> <dc> <dr> <el> <er> <ax> <ay> <az> <gz>`
  back at 10Hz (single ultrasonic reported as `dc`). The laptop shows the
  distance and an override warning in the video window, so data flows both ways.

### Wiring
```
OLED  SDA->A4  SCL->A5  VCC->5V  GND->GND   (0x3C)
HC-SR04 :  TRIG->D2  ECHO->D3
Follow LED : long leg->220Ω->D6, short->GND
LEFT  LED  : long leg->220Ω->D7, short->GND
RIGHT LED  : long leg->220Ω->D8, short->GND
```

Upload at 115200, close the Arduino Serial Monitor, then run the vision stack
pointed at the Uno's port: `python main.py --webcam --serial COM8`

> The MPU-6050 tip-over override is not in this sketch yet — reading the MPU over
I2C without a timeout can hang the loop if the connection is flaky. It will be added back
> once the bus is rock-solid.

## Bench test sketches (sensor bring-up, run individually)

| Sketch | Tests |
|---|---|
| `i2c_scan.ino` | Lists I2C devices — confirms OLED (0x3C) + MPU-6050 (0x68) |
| `test_oled.ino` | OLED only — clean text + counter |
| `test_mpu_oled.ino` | MPU-6050 tilt (pitch/roll) shown on OLED |
| `test_ultrasonic_oled.ino` | One HC-SR04 distance shown on OLED |
| `test_led.ino` | LED blink on D6 |
| `sensor_min.ino` | OLED + MPU + 1 ultrasonic + LED combined |
| `sensor_hub.ino` | OLED + MPU + 2 ultrasonics + LED combined |

## Libraries (Arduino IDE → Library Manager)

- Adafruit SSD1306, Adafruit GFX
- Adafruit MPU6050, Adafruit Unified Sensor (for the MPU sketches)

> Note: HC-SR04 echo connects straight to the 5V Uno here. On the real 3.3V
> ESP32 board, the echo line goes through a voltage divider (see hardware BOM).

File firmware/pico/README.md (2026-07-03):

# Raspberry Pi Pico — bench-test firmware (MicroPython)

Experimental stand-in for the ESP32. Reads the Pi's serial protocol and drives an
LED (and OLED, in `pico_main.py`).

- `pico_led_test.py` — minimal LED-only test for the `CMD` protocol.
- `pico_main.py` — LED + SSD1306 OLED, handles `CMD` and `ASL` messages.

## Known issue

Reading USB serial (`sys.stdin`) in standalone mode (running as `main.py` on boot,
MicroPico disconnected) is unreliable — see issue tracker. The **Arduino Uno is the
current bench stand-in**. The Pico is expected to work properly on the final robot
where the Pi 5 talks to it over the **hardware UART pins** (not USB).

## Setup

1. Flash MicroPython (`.uf2` from micropython.org) by holding BOOTSEL and copying
   the file onto the RPI-RP2 drive.
2. For the OLED: `mpremote mip install ssd1306`.

## Wiring

```
OLED VCC -> 3V3 (pin 36)    OLED SDA -> GP0 (pin 1)
OLED GND -> GND (pin 38)    OLED SCL -> GP1 (pin 2)

LED long leg -> 220Ω -> GP15 (pin 20)    LED short leg -> GND (pin 23)
```

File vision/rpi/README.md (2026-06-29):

# Philo — Vision & Control Stack

The high-level "brain" for Philo. Runs computer vision, decides how the robot
should move, and sends commands to the microcontroller (Arduino Uno as the ESP32
stand-in on the bench; ESP32 on the final PCB) over serial.

**Runs on a Raspberry Pi 5** (the robot's brain) *or* a laptop (for development
and for ASL, which needs MediaPipe). Same code on both — only the camera source
and serial port differ.

## What it does

1. **Person following** — YOLOv8n-pose finds the nearest person; bounding-box
   center steers left/right, box size sets speed (bigger = closer = slower).
2. **Gesture stop** — raise a wrist above the shoulder for 5 frames to halt;
   lower it for 5 frames to resume.
3. **ASL fingerspelling** — MediaPipe hand landmarks + a trained classifier
   recognize A–Z letters and flash them on the OLED. *(Laptop, or Pi with the
   Python 3.12 env — see below.)*
4. **Manual drive** — an Xbox controller drives the robot; tap **A** to toggle
   between AUTO (follow) and MANUAL (you drive). `--manual`.
5. **Obstacle override** — runs on the Arduino itself: if anything is within
   20 cm it forces a STOP, even in manual or while following. Safety doesn't
   depend on the link staying up.
6. *(Optional)* **Object labels** — YOLOv8 tags non-person objects. Off by
   default (heavy); enable with `--objects` on a laptop.

## Files

| File | Role |
|---|---|
| `main.py` | Main loop — following, gesture, ASL, manual, display |
| `tracker.py` | YOLOv8 pose (object model optional, off by default for Pi speed) |
| `controller.py` | Bounding box → `CMD` + gesture state machine |
| `uart.py` | Serial link to the microcontroller (`CMD` out, `STATUS` in) |
| `gamepad.py` | Xbox controller → differential drive (pygame) |
| `asl_features.py` | **Canonical** scale-invariant hand features (shared by train + infer) |
| `asl_from_dataset.py` | Train ASL model: `--dataset` (extract+train) or `--csv` (train from features) |
| `asl_collect.py` | Alternative: collect your own ASL samples from webcam |
| `asl_run.py` | Standalone ASL tester |
| `webcam_stream.py` | Laptop → MJPEG stream (lets the Pi use a remote camera via `--source`) |
| `test_link.py` | Pi→Arduino link check (follow/turn/stop, no camera) |
| `gamepad_test.py` | Print controller axes/buttons for mapping |

## Serial protocol

```
Pi  -> MCU :  CMD <left> <right> <flags>\n      # wheel speeds -255..255; flags bit0=coast,bit1=brake
MCU -> Pi  :  STATUS <vbat> <dl> <dc> <dr> <el> <er> <ax> <ay> <az> <gz>\n   (10 Hz)
Pi  -> MCU :  ASL <LETTER>\n                    # shows the letter on the OLED
```
115200 baud. Pi → Arduino over USB = `/dev/ttyACM0`. On the final robot, Pi → ESP32 = `/dev/serial0`. Windows bench = `COM#`.

## Running it

**On the Pi (the brain)** — USB webcam + Arduino on `/dev/ttyACM0`, ASL via the 3.12 env:
```bash
cd ~/Philobot/vision/rpi
DISPLAY=:0 ~/philo312/bin/python main.py --webcam --serial /dev/ttyACM0
```
Add `--manual` for Xbox-controller drive. `DISPLAY=:0` shows the detection window on the Pi's monitor.

**On a laptop** (full stack incl. ASL, Arduino on COM8):
```bash
python main.py --webcam --serial COM8
```

**Flags:** `--webcam` (USB/laptop cam) · `--source URL|index` (network/other camera) ·
`--serial PORT` · `--manual` (Xbox controller) · `--objects` (object labels, laptop) ·
`--no-display` (headless).

## Environments (Raspberry Pi 5)

The Pi ships with Python 3.13, but **MediaPipe has no 3.13 wheel**, so ASL needs a
side-by-side Python 3.12:

- `~/philo-venv` — Python 3.13, following only (ultralytics, opencv, pyserial, scikit-learn). No ASL.
- `~/philo312` — Python 3.12 (built from source via `make altinstall`), **full stack incl. MediaPipe**. Use this for everything. Note: `numpy<2` is pinned (MediaPipe requires it).

Install into a venv:
```bash
pip install ultralytics opencv-python mediapipe scikit-learn pyserial pygame "numpy<2"
```

Not committed (see `.gitignore`): model weights (`*.pt`, auto-download), `hand_landmarker.task`
(auto-downloads), `asl_model.pkl` and `asl_features.csv` (regenerate — below).

## Training the ASL model

Built from the [Kaggle ASL Alphabet dataset](https://www.kaggle.com/datasets/grassknoted/asl-alphabet).
Because a model pickled under one numpy version won't load under another (e.g. laptop
Python 3.13 / numpy 2 vs Pi numpy 1.26), training is split so the model is built in the
**same environment that runs it**:

```bash
# 1. Extract features (any machine with the dataset). Also writes asl_features.csv.
python asl_from_dataset.py --dataset "PATH/TO/asl_alphabet_train"

# 2. Train where you'll run it (e.g. copy the CSV to the Pi, then):
~/philo312/bin/python asl_from_dataset.py --csv asl_features.csv
```
`asl_features.csv` is version-independent, so extract once and retrain anywhere.

## Performance (Pi 5)

- **~14 FPS** following only · **~7–11 FPS** with ASL (MediaPipe adds load).
- The object-detection model is **off by default** — running it tanked the Pi to ~0.3 FPS.
- Pose `imgsz=256`. If you ever need more speed, export YOLO to **NCNN** (3–5× on Pi CPU).

## Notes

- **Camera:** USB webcam (plug-and-play, index 0). The `--source` + `webcam_stream.py`
  path can stream a remote camera over a network/direct-Ethernet link.
- **Laptop ↔ Pi:** the home router isolates WiFi clients, so the laptop reaches the Pi over a
  **direct Ethernet cable** (link-local `169.254.x.x`) for SSH/`scp`, or work on the Pi directly.
- The Arduino bench firmware (LEDs + OLED eyes + obstacle override) is in `firmware/arduino/`.

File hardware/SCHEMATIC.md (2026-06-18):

# Philo — Schematic Build Plan (KiCad)

**Purpose:** This is the schematic, written as text. Every component, every net, every connection. When you sit down in KiCad, you are transcribing this — not designing on the fly. Build it sheet by sheet, run ERC, then move to layout.

Reference designators match [BOM.md](BOM.md).

---

## How to Build This in KiCad (workflow)

1. **Create project:** `philo_pcb` → opens schematic editor (Eeschema).
2. **Use hierarchical sheets** (one per section below) or one flat sheet if you prefer. Six logical blocks: Power, MCU, Motor Drivers, Sensors, Companion (I2C mast), Interface.
3. **Place symbols** from the BOM. For modules (ESP32, D24V50F5, MPU-6050) use the matching module symbol/footprint — Espressif provides the ESP32 one; the D24V50F5 and MPU-6050 use a generic header footprint matching the module's pin layout/pitch.
4. **Wire per the net lists below.** Use named net labels (VBAT, +5V, +3V3, GND, etc.) instead of drawing every wire — much cleaner and less error-prone.
5. **Annotate** (assign reference designators), then **ERC** — fix every error and every meaningful warning.
6. **Assign footprints**, generate netlist, move to PCB layout (follow the layout checklist in hardware/README).

> Note: I can't drive the KiCad GUI for you (it's a desktop EDA tool). But this spec is complete enough that capture is mechanical. Build a sheet, ERC it, then ping me with anything that doesn't reconcile.

---

## Global Power Nets

Use these named nets everywhere instead of long wires:

- **VBAT** — raw battery, 6.4–8.4V (after fuse + reverse protection)
- **+5V** — D24V50F5 buck output (5A)
- **+3V3** — AMS1117 output
- **GND** — single net; the ground plane handles the star-ground topology in layout

---

## SHEET 1 — Power Input & Regulation

### Input protection chain
```
J1.+ (XT30)  →  F1 (7A polyfuse)  →  Q1 DRAIN (P-FET reverse protection) ;  Q1 SOURCE  →  VBAT
J1.-         →  GND
Q1 gate      →  GND through R (10k)
C9  (10µF ceramic)  : VBAT → GND   (at J1, fast transient)
C10 (100µF elec)    : VBAT → GND   (bulk)
```
**Reverse-polarity P-FET orientation (get this right — it is the #1 place this circuit is wired wrong):**
- **Drain → battery side** (incoming +, after the fuse)
- **Source → load side** (VBAT net)
- **Gate → GND via 10k**

Why: a P-FET body diode conducts drain→source. For protection it must conduct battery→load (so the board powers up) and block on reversal. That requires drain=battery, source=load. If you swap them, the board works normally but the body diode dumps reversed voltage into the Pi/ESP32 when the battery is plugged in backwards — i.e., it fails exactly when you need it. In normal operation source sits at ~VBAT, gate at 0V, so Vgs ≈ -7.4V (fully on); at 8.4V full charge Vgs ≈ -8.4V, within the AOD4185 ±20V gate rating (no Zener clamp needed at 2S). Verify the G/D/S pin order against the actual P-FET datasheet before placing the footprint.

### 5V rail — Pololu D24V50F5 (U2, 5V/5A module)
```
U2.VIN   ← VBAT
U2.GND   → GND
U2.VOUT  → +5V
U2.EN    → leave floating (internal pull-up = enabled) or tie to VIN
U2.PG    → optional (power-good open-drain; can drive an LED or leave unconnected)
C7 (1000µF low-ESR) : +5V → GND   (within 5mm of U2 VOUT — Pi inrush)
C8 (100nF)          : +5V → GND
```
Fixed 5.0V output — no trimpot to set. Match the footprint to the D24V50F5 pin layout (VIN, GND, VOUT, plus EN/PG). ~2A of headroom over the ~2.77A load.

### 3.3V rail — AMS1117-3.3 (U3)
```
U3.IN  ← +5V          (NOT VBAT — locked thermal decision)
U3.OUT → +3V3
U3.GND → GND
C3 (10µF) + C5 (100nF) : +5V (U3 in) → GND
C4 (10µF) + C6 (100nF) : +3V3 (U3 out) → GND
```

### Battery sense divider
```
VBAT → R12 (10k) → node "VBAT_SENSE" → R13 (3.3k) → GND
C18 (100nF) : VBAT_SENSE → GND     (filter)
VBAT_SENSE → U1.GPIO36
```

---

## SHEET 2 — MCU (ESP32-WROOM-32, U1)

### Power & boot
```
U1.3V3   ← +3V3
U1.GND   ← GND (all GND pins + thermal pad)
C1 (10µF) + C2 (100nF) : +3V3 → GND, close to U1.3V3
U1.EN    ← R9 (10k) to +3V3 ; C17 (1µF) EN→GND ; SW2 (RESET) EN→GND
U1.GPIO0 ← R11 (10k) to +3V3 ; SW1 (BOOT) GPIO0→GND
```

### Programming header (J_PROG, 6-pin)
```
J_PROG.1 = +3V3
J_PROG.2 = GND
J_PROG.3 = U1.EN
J_PROG.4 = U1.GPIO0
J_PROG.5 = U1.TXD0 (GPIO1)
J_PROG.6 = U1.RXD0 (GPIO3)
```
Manual flashing: hold BOOT, tap RESET, release BOOT. (Optional: add the 2-transistor DTR/RTS auto-reset circuit later — not required.)

### Status LED
```
U1.GPIO2 → R10 (100Ω) → D1 (LED) → GND
```
GPIO2 is a strapping pin (must not be held high at boot). LED to GND with series resistor is fine — it does not force the pin high. Do not add a pull-up here.

### ESP32 pin map (locked — see PRE_BUILD_LOCK A4)
| Function | GPIO | Net name |
|---|---|---|
| Left PWM | 25 | PWM_L |
| Left IN1 | 26 | L_IN1 |
| Left IN2 | 27 | L_IN2 |
| Right PWM | 32 | PWM_R |
| Right IN1 | 33 | R_IN1 |
| Right IN2 | 14 | R_IN2 |
| Left encoder | 34 | ENC_L |
| Right encoder | 35 | ENC_R |
| US center trig | 5 | TRIG_C |
| US center echo | 18 | ECHO_C |
| US left trig | 19 | TRIG_L |
| US left echo | 4 | ECHO_L |
| US right trig | 13 | TRIG_R |
| US right echo | 23 | ECHO_R |
| I2C SDA | 21 | SDA |
| I2C SCL | 22 | SCL |
| UART TX | 17 | ESP_TX |
| UART RX | 16 | ESP_RX |
| Battery ADC | 36 | VBAT_SENSE |
| Status LED | 2 | LED |

---

## SHEET 3 — Motor Drivers (U4, U5)

**Architecture: 4 motors, 4 channels, 2 chips. Each motor = one channel. Left pair shares control signals; right pair shares control signals.**

### Common to both TB6612FNG
```
U4.VM, U5.VM   ← VBAT
U4.VCC, U5.VCC ← +3V3 ; C13/C14 (100nF) each VCC → GND
U4.STBY, U5.STBY ← +3V3   (tie high — drivers always enabled)
U4.GND, U5.GND ← GND (+ exposed pad to GND pour)
C11 (470µF) : VBAT → GND at U4.VM (within 3mm)
C12 (470µF) : VBAT → GND at U5.VM (within 3mm)
```

### Control signal fan-out (the key wiring)
```
PWM_L (GPIO25) → U4.PWMA  AND  U5.PWMA      (both left motors)
L_IN1 (GPIO26) → U4.AIN1  AND  U5.AIN1
L_IN2 (GPIO27) → U4.AIN2  AND  U5.AIN2

PWM_R (GPIO32) → U4.PWMB  AND  U5.PWMB      (both right motors)
R_IN1 (GPIO33) → U4.BIN1  AND  U5.BIN1
R_IN2 (GPIO14) → U4.BIN2  AND  U5.BIN2
```
Each ESP32 output drives two high-impedance CMOS inputs — fine.

### Motor outputs
```
U4.AO1, U4.AO2 → J_ML_F   (left-front motor)
U5.AO1, U5.AO2 → J_ML_R   (left-rear motor)
U4.BO1, U4.BO2 → J_MR_F   (right-front motor)
U5.BO1, U5.BO2 → J_MR_R   (right-rear motor)
```
Mark polarity on silkscreen at each motor connector. If a motor runs backward, swap its two wires — never fix in firmware.

### Encoders (one per side)
```
J_ENC_L: +3V3, GND, out → ENC_L (GPIO34) ; C15 (100nF) ENC_L → GND
J_ENC_R: +3V3, GND, out → ENC_R (GPIO35) ; C16 (100nF) ENC_R → GND
```
Only the front motor's encoder per side is read (GPIO34/35 are input-only, fine for counting). Add 10k pull-up to +3V3 on each encoder line if the encoder output is open-collector (check the specific JGA25-370 encoder variant).

---

## SHEET 4 — Sensors

### Ultrasonic ×3 (HC-SR04) — echo MUST be divided
For each sensor (center/left/right), the echo divider:
```
J_US.Echo (5V) → R_series (1k) → node ECHO_x → R_gnd (2k) → GND
node ECHO_x → ESP32 echo pin
J_US.Trig ← ESP32 trig pin   (3.3V direct, no divider)
J_US.VCC  ← +5V
J_US.GND  ← GND
```
| Sensor | Trig net (pin) | Echo net (pin) | Divider R |
|---|---|---|---|
| Center (J_US1) | TRIG_C (5) | ECHO_C (18) | R1 1k / R4 2k |
| Left (J_US2) | TRIG_L (19) | ECHO_L (4) | R2 1k / R5 2k |
| Right (J_US3) | TRIG_R (13) | ECHO_R (23) | R3 1k / R6 2k |

### IMU (MPU-6050, U6)
```
U6.VCC ← +3V3
U6.GND ← GND
U6.SDA ↔ SDA (GPIO21)
U6.SCL ↔ SCL (GPIO22)
U6.AD0 → GND   (address 0x68)
```

### I2C pull-ups (shared by IMU + both OLEDs)
```
R7 (4.7k): SDA → +3V3
R8 (4.7k): SCL → +3V3
```
One pull-up pair serves the whole bus — do not add more on the OLED modules (remove/ignore their onboard pull-ups if present, or accept the parallel value; check it stays near 2–4.7k effective).

---

## SHEET 5 — Companion (I2C Mast Header)

Both OLED eyes live on the mast and share the I2C bus via one 4-wire header.
```
J_MAST.1 = +3V3
J_MAST.2 = GND
J_MAST.3 = SDA
J_MAST.4 = SCL
```
OLED1 set to 0x3C, OLED2 set to 0x3D (address pad on each module). Driven by ESP32 core 1 (firmware). No additional PCB components.

> Audio (speaker) is NOT on this PCB — it lives on the Pi (USB). Nothing to wire here.

---

## SHEET 6 — Interface to Raspberry Pi

```
J_PI_PWR.1 = +5V   → Pi GPIO pin 2 (5V)
J_PI_PWR.2 = GND   → Pi GPIO pin 6 (GND)

J_UART.1 = ESP_TX (GPIO17) → Pi GPIO pin 10 (RXD)
J_UART.2 = ESP_RX (GPIO16) ← Pi GPIO pin 8 (TXD)
J_UART.3 = GND
```
UART is 3.3V on both ends (ESP32 and Pi) — no level shifting needed. Do not power the Pi over USB-C; use this 5V header.

---

## Net List Summary (master reference)

| Net | Connects |
|---|---|
| VBAT | F1/Q1 out, U2.IN, U4.VM, U5.VM, C9, C10, C11, C12, R12 |
| +5V | U2.OUT, U3.IN, J_PI_PWR.1, J_US VCC ×3, C7, C8 |
| +3V3 | U3.OUT, U1.3V3, U4.VCC, U5.VCC, STBY ×2, U6.VCC, J_MAST.1, pull-ups, C1/C3/C4 |
| GND | everything; ground plane |
| PWM_L / L_IN1 / L_IN2 | GPIO25/26/27 → U4 & U5 channel A inputs |
| PWM_R / R_IN1 / R_IN2 | GPIO32/33/14 → U4 & U5 channel B inputs |
| SDA / SCL | GPIO21/22 ↔ U6, J_MAST, R7/R8 |
| ECHO_C/L/R | GPIO18/4/23 (after dividers) |
| TRIG_C/L/R | GPIO5/19/13 |
| ENC_L / ENC_R | GPIO34/35 |
| VBAT_SENSE | GPIO36 (via R12/R13) |
| ESP_TX / ESP_RX | GPIO17/16 ↔ J_UART |
| LED | GPIO2 → R10 → D1 → GND |

---

## Pre-Layout ERC Checklist

- [ ] Every power pin connected to a power net (no floating VCC)
- [ ] All GND pins + IC exposed pads on GND
- [ ] No net with only one connection (ERC "single pin net")
- [ ] STBY pins tied to +3V3 (not floating — drivers disabled if floating)
- [ ] EN has pull-up + cap; GPIO0 has pull-up
- [ ] Both I2C lines have exactly one pull-up pair
- [ ] All 3 echo lines pass through a divider before the ESP32 pin
- [ ] AMS1117 input net is +5V, not VBAT
- [ ] No GPIO double-assigned (cross-check against pin map table)
- [ ] ERC reports zero errors before moving to layout

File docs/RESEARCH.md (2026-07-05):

# Research & References

Sources the team used while designing Philo — mechanical inspiration, academic
background on person-following robots, and component datasheets. Kept here so
the reasoning behind design decisions is traceable, and so anyone reviewing the
project (or asking "did you actually understand this or just copy it?") can see
the source material.

---

## Mechanical Reference Robots

Used by [@hummos430](https://github.com/hummos430) for chassis layout,
differential-drive motor mounting, and general proportions.
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

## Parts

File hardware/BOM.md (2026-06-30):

# Philo — Bill of Materials (Complete)

**Status: Schematic complete, ERC clean, PCB layout complete, DRC clean, Gerbers exported. Ready to order.**

This is the authoritative parts list matching the annotated KiCad schematic. Reference designators reflect post-annotation numbering.

---

## Active Components

| Ref | Part | Value / Spec | Footprint | Qty | Notes |
|---|---|---|---|---|---|
| U8 | ESP32-WROOM-32 | 240MHz, 4MB flash | RF_Module:ESP32-WROOM-32 | 1 | Castellated SMD module |
| J8 | Pololu D24V50F5 | 5.0V fixed out, 5A buck | PinHeader_1x05_P2.54mm | 1 | Complete module — no external inductor/feedback needed. VIN←VBAT, VOUT→+5V |
| U5 | AMS1117-3.3 | 3.3V LDO, 800mA | SOT-223-3_TabPin2 | 1 | Input from **+5V rail**, NOT VBAT — thermal lock decision |
| U6 | TB6612FNG | Dual H-bridge, 1.2A/ch | SSOP-24_5.3x8.2mm_P0.65mm | 1 | Left-front + right-front motors |
| U7 | TB6612FNG | Dual H-bridge, 1.2A/ch | SSOP-24_5.3x8.2mm_P0.65mm | 1 | Left-rear + right-rear motors |
| U1 | MPU-6050 (GY-521 module) | 6-axis IMU, I2C | PinHeader_1x08_P2.54mm | 1 | Address 0x68 (AD0→GND). Use GY-521 breakout |
| Q2 | AOD4185 P-channel MOSFET | Vds>30V, 10A | TO-252-3_TabPin2 | 1 | Reverse-polarity protection. Drain=battery side, Source=VBAT rail |
| D1 | Status LED | Any color | LED_0805_2012Metric | 1 | GPIO2 → R11 (100Ω) → LED → GND |

---

## Off-Board Modules (connect via headers)

| Part | Spec | Qty | Connector | Est. Price | Notes |
|---|---|---|---|---|---|
| OLED display | SSD1306, 128x64, I2C, 0.96 inch | 2 | J4 (J_MAST) | ~$4 ea (Amazon) | One at 0x3C (telemetry / left eye), one at 0x3D (right eye). Set address via solder jumper on back of module. Mounted on camera mast as eyes. **Buy 2.** |
| HC-SR04 | Ultrasonic, 5V | 3 | J1/J2/J3 | ~$1 ea (Amazon) | Echo lines go through on-board 1k/2k dividers |
| Raspberry Pi 5 (4GB) | — | 1 | J5 + J6 | on hand | 5V from rail; UART for commands. On hand with active cooler. ⚠️ Pi 5 draws up to 4.5A — D24V50F5 at 5A is near capacity under full inference load. |
| Pi Camera Module 3 | 12MP autofocus, CSI | 1 | Pi CSI port | on hand | On hand, confirmed working. Not on this PCB — connects to Pi CSI ribbon. |
| USB speaker | Small amplified | 1 | Pi USB | ~$8 (Amazon) | Audio is Pi-side only. See vision README for playback code. |
| 2S LiPo 2200mAh | 7.4V nominal, XT30 plug | 1 | J7 (XT30) | ~$14 (Amazon) | **2S only — NOT 4S.** Soft-pack preferred for weight. |
| JGA25-370 motors | 6V, 200RPM, 4mm D-shaft | 4 | J9/J10/J11/J12 | ~$8 ea (AliExpress) | 2 per TB6612FNG. Confirm 4mm D-shaft (not N20 3mm). |
| Encoders | One per side | 2 | J13/J14 | included with motors | GPIO34 (left), GPIO35 (right). |

---

## Passives

| Ref | Value | Footprint | Qty | Purpose |
|---|---|---|---|---|
| C1,C2,C3,C18,C20,C21,C25,C26,C28,C31 | 100nF | C_0603_1608Metric | 10 | Decoupling / HF bypass |
| C17,C19,C23,C32 | 10µF | C_0805_2012Metric | 4 | Bulk ceramic decoupling |
| C30 | 1µF | C_0603_1608Metric | 1 | ESP32 EN pin delay cap |
| C24 | 100µF 16V electrolytic | CP_Radial_D6.3mm_P2.50mm | 1 | VBAT input bulk |
| C27,C29 | 470µF 16V electrolytic (low ESR) | CP_Radial_D10.0mm_P5.00mm | 2 | TB6612FNG VM bulk (one per chip, within 3mm) |
| C22 | 1000µF 16V electrolytic (low ESR) | CP_Radial_D12.5mm_P5.00mm | 1 | D24V50F5 5V output bulk (Pi inrush) |
| R1,R3,R8 | 1kΩ | R_0603_1608Metric | 3 | HC-SR04 echo divider — series |
| R2,R7,R9 | 2kΩ | R_0603_1608Metric | 3 | HC-SR04 echo divider — to GND |
| R4,R5,R10,R12 | 10kΩ | R_0603_1608Metric | 4 | Gate resistor (Q2), EN pull-up, GPIO0 pull-up, VBAT sense |
| R6 | 3.3kΩ | R_0603_1608Metric | 1 | Battery sense divider — GND side |
| R11 | 100Ω | R_0603_1608Metric | 1 | Status LED current limit |
| R13,R14 | 4.7kΩ | R_0603_1608Metric | 2 | I2C SDA/SCL pull-ups (shared by IMU + both OLEDs) |

---

## Protection & Switches

| Ref | Part | Value | Footprint | Qty | Notes |
|---|---|---|---|---|---|
| F2 | Polyfuse PPTC | 7A hold | CP_Radial_D10.0mm_P5.00mm | 1 | Littelfuse RGEF700. **7A not 5A** — avoids pre-trip sag |
| SW1 | Tactile switch | — | SW_PUSH_6mm (THT) | 1 | RESET — EN → GND |
| SW2 | Tactile switch | — | SW_PUSH_6mm (THT) | 1 | BOOT — GPIO0 → GND |
| TP1–TP6 | Test point | — | TestPoint_Pad_D1.5mm | 6 | VBAT, +5V, +3V3, GND×2, ESP_TX, ESP_RX |

---

## Connectors

| Ref | Value | Footprint | Qty | Connects |
|---|---|---|---|---|
| J7 | XT30 battery | AMASS_XT30PW-F Horizontal | 1 | Battery +/− input |
| J8 | D24V50F5 module | PinHeader_1x05_P2.54mm | 1 | Buck regulator (VIN, GND, VOUT, EN, PG) |
| J1,J2,J3 | HC-SR04 center/left/right | PinHeader_1x04_P2.54mm | 3 | Ultrasonic sensors |
| J4 | J_MAST | PinHeader_1x04_P2.54mm | 1 | I2C mast: +3V3, GND, SDA, SCL |
| J5 | J_PI_PWR | PinHeader_1x02_P2.54mm | 1 | +5V + GND to Pi |
| J6 | J_UART | PinHeader_1x03_P2.54mm | 1 | ESP_TX, ESP_RX, GND to Pi |
| J9,J10 | J_ML_F, J_MR_F | PinHeader_1x02_P2.54mm | 2 | Front motor outputs (U6) |
| J11,J12 | J_ML_R, J_MR_R | PinHeader_1x02_P2.54mm | 2 | Rear motor outputs (U7) |
| J13,J14 | ENC_L, ENC_R | PinHeader_1x03_P2.54mm | 2 | Encoders: +3V3, GND, signal |

---

## Power Rails Summary

| Rail | Source | Feeds |
|---|---|---|
| VBAT (6.4–8.4V) | J7 → F2 → Q2 | TB6612FNG VM, D24V50F5 input, battery-sense divider |
| +5V (5.0V, 5A) | D24V50F5 (J8) | Raspberry Pi, AMS1117 input, HC-SR04 VCC |
| +3V3 (3.3V, 800mA) | AMS1117 (U5) | ESP32, MPU-6050, TB6612FNG VCC/STBY, OLEDs, pull-ups, LED |

**Locked decisions:** AMS1117 fed from +5V not VBAT (thermal); 7A polyfuse; one motor per H-bridge channel; OLEDs on existing I2C bus; audio off-board on Pi.

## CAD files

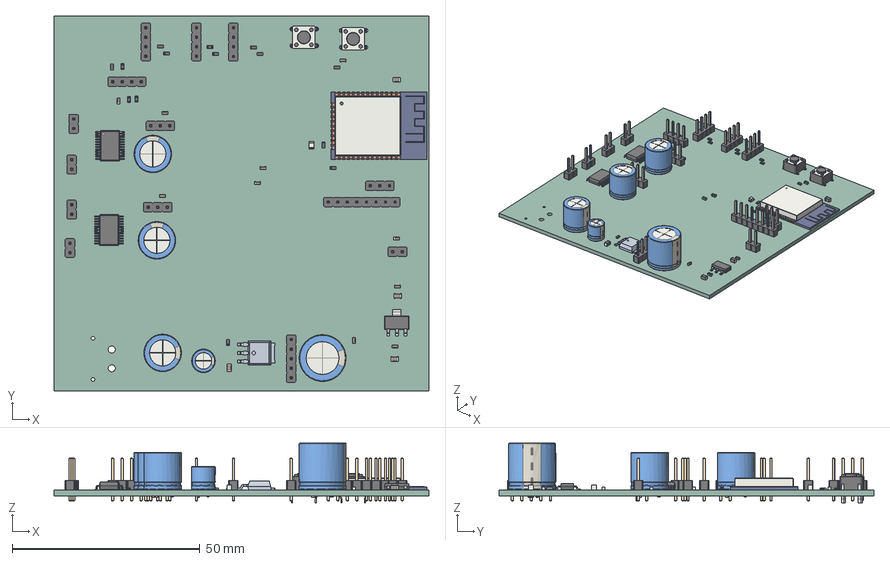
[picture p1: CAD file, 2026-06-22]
mechanical/Philo- main.step
100.0 x 100.0 x 16.0 mm
PinHeader_1x02_P2.54mm_Vertical x 5
PinHeader_1x04_P2.54mm_Vertical x 4
R_0603_1608Metric x 14
SW_PUSH_6mm x 2
PinHeader_1x08_P2.54mm_Vertical
C_0603_1608Metric x 10
SSOP-24_5.3x8.2mm_P0.65mm x 2
C_0805_2012Metric x 4
PinHeader_1x03_P2.54mm_Vertical x 3
ESP32-WROOM-32
CP_Radial_D10.0mm_P5.00mm x 3
CP_Radial_D6.3mm_P2.50mm
PinHeader_1x05_P2.54mm_Vertical
CP_Radial_D12.5mm_P5.00mm
Philo- main 1.43.1
LED_0805_2012Metric
SOT-223
Philo- main_PCB

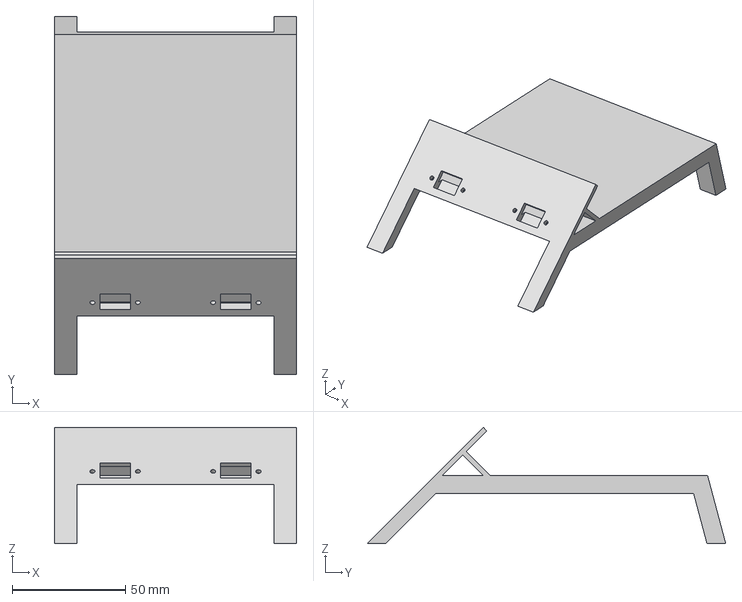
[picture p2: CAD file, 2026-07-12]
mechanical/stl/External2.step
106.7 x 158.0 x 51.2 mm

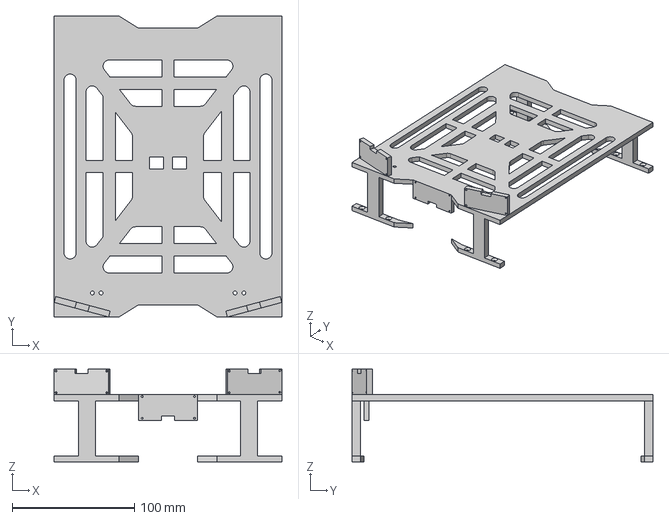
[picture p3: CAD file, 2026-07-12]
mechanical/stl/Top.step
186.0 x 246.0 x 76.0 mm

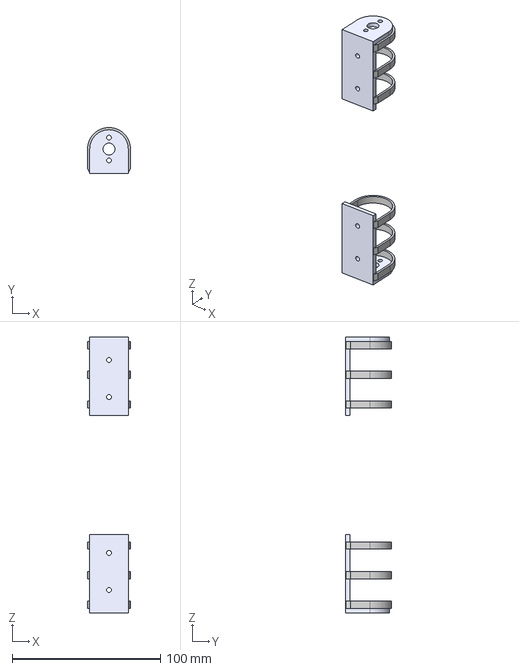
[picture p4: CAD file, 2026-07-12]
mechanical/stl/JGA25-370 motor bracket.step
29.0 x 31.0 x 186.0 mm

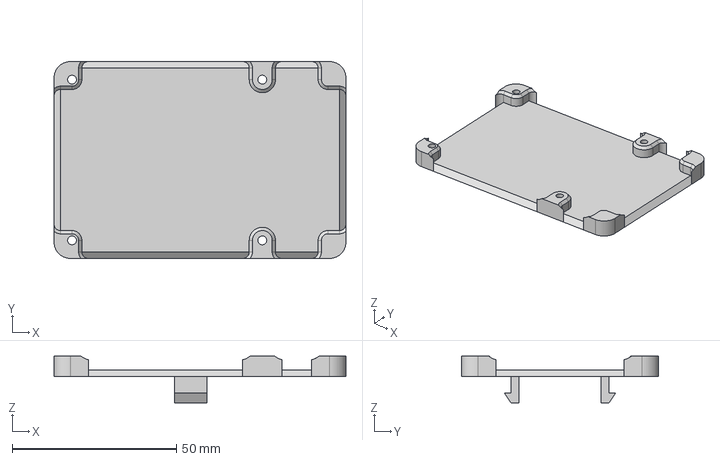
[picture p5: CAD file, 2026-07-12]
mechanical/stl/Raspberrypi Case.step
89.0 x 60.0 x 14.2 mm

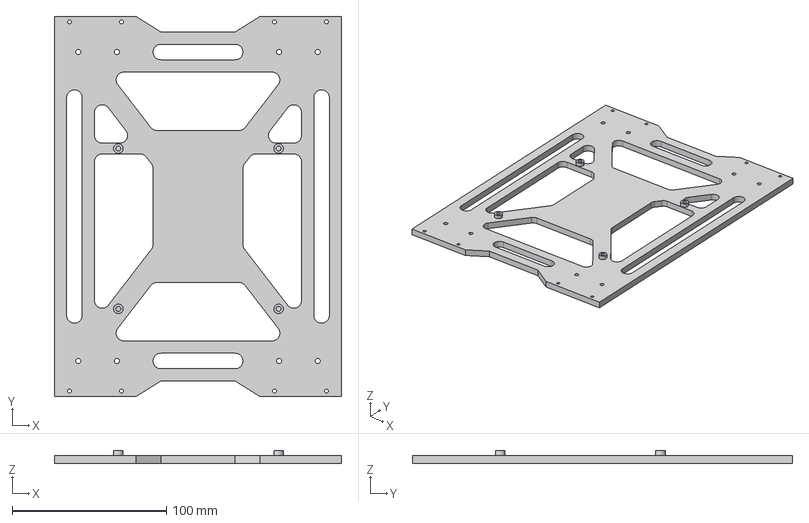
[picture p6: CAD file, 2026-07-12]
mechanical/stl/Bottom Plate.step
186.0 x 246.0 x 8.10 mm

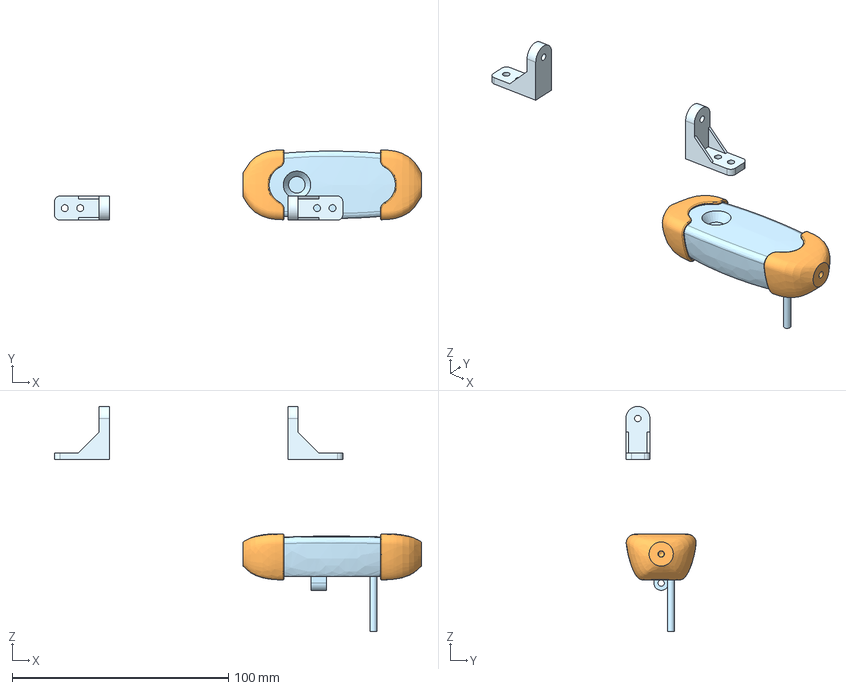
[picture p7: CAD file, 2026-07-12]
mechanical/stl/C270 Mount (1).step
169.8 x 32.6 x 104.1 mm

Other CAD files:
mechanical/stl/Bottom Plate.stl
mechanical/stl/C270 Mount (1).stl
mechanical/stl/External2.stl
mechanical/stl/JGA25-370 motor bracket.stl
mechanical/stl/Raspberrypi Case.stl
mechanical/stl/Top.stl

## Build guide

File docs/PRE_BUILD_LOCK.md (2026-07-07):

# Philo — Pre-Build Lock List

**Purpose:** This is the design freeze document. Before Gerbers go to JLCPCB and chassis printing begins, this file defines what is FROZEN (changing it costs a PCB respin or chassis reprint), what is TUNABLE (dial in during testing, no commitment needed now), and which upgrades are worth doing versus which are overengineering to ignore.

**Read this before the Week 3 PCB order. Once the board is fabricated, the FROZEN section is locked.**

---

## How to Use This Document

A design freeze is the point where you stop improving and start building. Past this point:
- Changing a FROZEN item means re-spending money (PCB ~$15 + 10 days, or a chassis reprint of several hours)
- Changing a TUNABLE item is just editing code or a slicer setting — costs nothing

The discipline is: **resist the urge to keep "improving" frozen things.** Every late change to a frozen item is a chance to introduce a new bug into a system that was working. Improvements go into a V2 list, not into the board you are about to order.

---

## SECTION A — FROZEN (do not change after PCB order / chassis print)

These decisions are load-bearing. Other parts of the design are built around them. Changing one cascades into reprints, respins, or reorders.

### A1 — Motor: JGA25-370, 6V, 200 RPM, 4mm D-shaft
**Why frozen:** Everything depends on this. Wheel hub bore (4mm D), motor mount pocket (25mm body), torque math (1.8 kg·cm stall), motor mount hole spacing, and the entire weight/power budget are sized to this exact motor.
**Confirm before freeze:** hummos430 must measure the *actual ordered motor* with calipers — body diameter, shaft diameter, and mounting hole spacing — and confirm they match the spec. Order the motors FIRST so this can be verified before the chassis is finalized.

### A2 — Top speed is locked at ~0.52 m/s by this motor choice — decide NOW if that's enough
**This is the one freeze decision people regret.** The JGA25-370 is a 6V motor. At 2S (7.4V) it already runs 23% over rated voltage — acceptable. Going to 3S (11.1V) for more speed would run it 85% over rated, which shortens motor life badly and is not a real option for *this* motor.

So the honest situation: **with these motors, 2S is correct and 0.52 m/s is your ceiling.** If 0.52 m/s (a casual walk the person slows down for) is not acceptable for your demo, the fix is a *12V-rated motor*, which is a motor change — and a motor change must happen BEFORE the chassis and PCB are frozen because it changes shaft size, mount dimensions, and current budget.

**Decision required now:** Accept 0.52 m/s with JGA25-370, OR switch to a 12V-rated gear motor before freeze. Do not discover this gap after the chassis is printed.

### A3 — PCB outer dimensions and mounting hole positions
**Why frozen:** The chassis plate is designed with cutouts and standoff holes that match the board exactly. The board outline in KiCad must match the dimensions handed to hummos430. If the board grows by 5mm after the chassis is printed, it won't fit.
**Locked:** Board grew from the original 100×100mm to **116×116mm** to make room for 4x real M3 mounting holes (the original layout had no board-edge clearance for them). Hole coordinates are in `mechanical/README.md` section "1. Main Chassis Plate." DRC and ERC both verified clean (0 errors) after the resize.
**Confirm before freeze:** Hardware team and hummos430 sign off that the chassis plate is designed against 116×116mm and the exact hole coordinates in `mechanical/README.md`, not the old 100×100mm figure.

### A4 — ESP32 GPIO pin assignments
**Why frozen:** Once the PCB is routed, the pins are physically wired. The firmware adapts to the board, not the other way around. We already resolved the GPIO 21/22 double-assignment conflict (I2C vs ultrasonic). That fix is locked.
**Locked map:** Motor PWM/dir on 25/26/27 and 32/33/14, encoders on 34/35, ultrasonic triggers on 5/13/19, echoes on 4/18/23, I2C on 21/22 (now carries MPU-6050 + 2 OLED eyes — no new pins), UART on 16/17, battery ADC on 36, status LED on 2. Verify against the KiCad schematic before routing. Note: the ESP32 is essentially full — the only remaining free pins (0, 12, 15) are boot-strapping pins, which is why audio lives on the Pi, not here.

### A5 — Power architecture
**Why frozen:** This is the part that took the most review to get right. Locked:
- 5V rail: Pololu D24V50F5 buck (5V/5A, fixed output), 1000µF + 100nF output caps. Upgraded from the 3A MP1584EN for headroom on the Pi rail (Pi 2.5-3A + AMS cascade + possible USB speaker)
- 3.3V rail: AMS1117-3.3 fed **from the 5V rail, not VBAT** (thermal fix — 62°C vs 135°C junction)
- 7A-rated polyfuse on VBAT input (not 5A — avoids pre-trip voltage sag)
- Reverse-polarity P-MOSFET on VBAT
- TB6612FNG ×2, thermal pad to GND copper pour
- 470µF bulk cap at each TB6612FNG VM pin
- Battery voltage sense divider (10k/3.3k) to GPIO36

### A6 — Ground architecture
**Why frozen:** Solid ground plane on bottom layer, via stitching every 10mm, single star entry at XT30 negative. This is a layout decision baked into the board. Cannot be added after fabrication.

### A7 — Connectors and battery form factor
**Why frozen:** XT30 battery connector and the 2S 2200mAh soft-pack form factor define the battery bay dimensions in the chassis. Motor and sensor headers define footprint placement.
**Confirm before freeze:** Get the *physical dimensions of the actual battery ordered* — soft-pack sizes vary. Size the bay to the real pack, not the nominal spec.

### A8 — Camera mast height (380mm total) and tilt (20–25° upward)
**Why frozen:** This is the geometry that makes gesture detection physically possible. The chassis mast-mounting point is designed for this height. The vision system's keypoint visibility math assumes it. Lower the mast and the camera sees knees instead of arms — gesture detection stops working entirely.

### A9 — HC-SR04 echo voltage dividers (1k/2k) and the level-shift requirement
**Why frozen:** These protect the ESP32 GPIO from 5V echo signals. 6 resistors on the schematic. Not optional, not changeable post-fab.

### A10 — Companion eyes + audio architecture (added at design freeze)
**Why frozen:** Decided before the board and chassis are locked, so the I2C bus and chassis cutouts can be designed in now rather than retrofitted.
- **Eyes:** 2x SSD1306/SH1106 OLED (128x64, I2C) at addresses 0x3C and 0x3D, on the *existing* I2C bus alongside the MPU-6050 (0x68). Three I2C devices total. No new ESP32 GPIO pins. Driven by the ESP32 on **core 1** (a full refresh is ~23ms and must not run in the control loop on core 0).
- **Audio:** driven by the **Raspberry Pi**, not the ESP32 (the ESP32 has no safe free pins left — only boot-strapping pins remain). Pre-recorded WAV clips via aplay, triggered on state transitions. The custom PCB carries audio only as a 5V power allowance if the speaker taps the 5V rail.
- **Chassis impact (hummos430):** two OLED-sized cutouts in the front of the mast head (active area ~22x11mm, module ~27x27mm) and a speaker grille. These must be in the chassis design before printing.
- **Live ChatGPT voice = explicitly V2.** Not in this build (see D7).

---

## SECTION B — TUNABLE (leave open, dial in during integration/testing weeks)

Do NOT try to perfect these before the build. They are software values or slicer settings. You will tune them on the real robot in weeks 5–8, and the real robot will tell you the right values faster than any amount of planning.

| Parameter | Starting value | Where it's tuned |
|---|---|---|
| PID gains | Kp=1.0, Ki=0.1, Kd=0.05 | Week 6, on the bench with wheels off the ground first |
| Vision dead zone | ±0.15 | Week 7, watching follow behavior |
| Offset EMA alpha | 0.3 | Week 7, if oscillation appears |
| Bbox height distance thresholds | 0.2 / 0.5 / 0.7 | Week 7, with real person at known distances |
| Inference image size | imgsz=320 (try 224) | Week 5, benchmark FPS vs detection range |
| Soft-start ramp time | 200ms | Week 6, watching motor startup current |
| Ultrasonic stop/slow thresholds | 25cm / 30cm | Week 7, in the actual demo room |
| Ultrasonic scan gap | 60ms | Week 6, confirm no crosstalk |
| Watchdog timeout | 500ms | Week 7, balance safety vs responsiveness |
| Gesture debounce frames | 5 | Week 6, balance responsiveness vs false triggers |
| Follow speed values | 150 turn / variable forward | Week 7 |
| Print infill on non-structural parts | 20–25% | Whenever, based on weight |

**Rule:** if it lives in code or the slicer, it is not a freeze decision. Stop debating these now.

---

## SECTION C — WORTH-IT UPGRADES (small additions, real payoff)

These are cheap, low-risk, and genuinely improve the build. Add them to the PCB/build NOW while it's free to do so — most cost nothing once the board is being designed anyway.

### C1 — Test points on the PCB ⭐ (highest value, near-zero cost)
Add labeled test points (just exposed pads or small header pins) for: VBAT, 5V, 3.3V, GND (×2), UART TX, UART RX, and one ESP32 GPIO. When something doesn't work during bring-up — and something always doesn't — these turn a multi-hour debugging session into a 30-second probe. This is the single best thing you can add to a first-revision board.

### C2 — 10µF ceramic cap at the XT30 input
A ceramic responds faster than the bulk electrolytic to the initial edge of a motor transient. One part, a few cents, slightly cleaner VBAT. Worth it.

### C3 — Aluminum heatsink on the Pi BCM2711 SoC
Already in the failure-mode list (#10). Confirm it's actually in the build, not just on paper. Self-adhesive, ~$2, prevents thermal throttling that would drop your YOLO FPS mid-demo.

### C4 — Break out 2–3 spare ESP32 GPIOs to a header
Costs nothing on the board. If you discover during integration that you need one more sensor or a debug LED, you have pins available without a respin.

---

## SECTION D — OVERENGINEERING (do NOT do these — they add risk or scope, not value)

Equally important as knowing what to add: knowing what to refuse. Each of these has been considered and rejected for good reason.

### D1 — ❌ LC filter on the motor rail
Suggested in review. **Do not do this.** An inductor in series with the motor current path fights the current change during reversal and generates a voltage spike that can exceed what the TB6612FNG flyback diodes and bulk caps handle. It makes the transient problem *worse*, not better. The 470µF bulk caps are the correct solution.

### D2 — ❌ "Power domain separation" beyond what exists
Review flagged this as a missing upgrade. It isn't missing — we already have it. The D24V50F5 is the dedicated logic buck, motors run directly from VBAT through the TB6612FNG, bulk caps isolate the transient domains. The separation being asked for is already in the design.

### D3 — ❌ Coral USB / Hailo / Jetson for faster inference
The ~200ms latency ("laggy dog" feel) is real but is an accepted characteristic, not a defect. Adding an AI accelerator is a major scope, cost, and integration change for a demo that works fine at current speed. V2 territory.

### D4 — ❌ A 4th ultrasonic sensor / wider sensor array
The ±15–30° side gap is acceptable for a living-room demo where obstacles are walls, furniture edges, and table legs approaching from the front. More sensors means more crosstalk timing complexity and more board space for marginal benefit.

### D5 — ❌ Person re-identification / shirt-color tracking
"Follow the largest bounding box" is the V1 approach and it's documented with its limitation. True re-ID is a hard research problem. Don't open it for this timeline.

### D6 — ❌ SLAM / mapping
Already rejected earlier in the project. Reactive obstacle avoidance is the right scope. Don't reintroduce it.

### D7 — ❌ Live ChatGPT voice conversation (for V1)
A real voice pipeline (mic → speech-to-text → LLM API → text-to-speech → speaker) is a second project. It competes with YOLOv8 for the Pi's already-maxed CPU, adds a microphone hardware chain, and makes the demo depend on a live internet connection and external API uptime. The companion feel is delivered by eyes + pre-recorded clips (A10) at near-zero risk. Live conversation is a post-demo V2 goal. To keep the door open cheaply: leave one Pi USB port free for a future mic. Build nothing else for it now.

### D8 — ❌ 4S battery / drivetrain redesign (for V1)
A 4S pack (16.8V full charge) exceeds the TB6612FNG absolute max (15V) and would destroy the 6V JGA25-370 motors. Using it requires 12V motors + a higher-voltage driver (or a motor-rail buck) + a larger chassis — a 1–2 week redesign of frozen items. Decided against for V1; a ~$15 2S 2200mAh pack keeps the proven design intact. The 4S is a V2 option if a bigger/faster build is pursued later.

---

## SECTION E — Freeze Sign-Off Checklist

Before the board is ordered (target: Week 3), confirm every item:

- [ ] Motors ordered and physically measured (A1) — caliper-verified body, shaft, hole spacing
- [ ] Speed decision made and accepted (A2) — 0.52 m/s with JGA25-370, OR motor swapped before freeze
- [ ] PCB outline and standoff holes agreed in writing between hardware and hummos430 (A3)
- [ ] ESP32 pin map verified against KiCad schematic, no conflicts (A4) — OLED eyes use existing I2C, no new pins
- [ ] Power architecture matches A5 exactly (AMS1117 from 5V, 7A fuse, thermal pads)
- [ ] Ground plane + star ground in the layout (A6)
- [ ] Actual battery measured, bay sized to it (A7) — 2S 2200mAh confirmed, NOT the 4S
- [ ] Camera mast geometry locked at 380mm / 20–25° (A8)
- [ ] HC-SR04 dividers on all 3 echo lines (A9)
- [ ] OLED eyes at 0x3C/0x3D on I2C bus; mast-head eye cutouts in chassis design (A10)
- [ ] Speaker grille in chassis design; speaker powered from Pi USB or 5V rail with budget noted (A10)
- [ ] Test points added (C1)
- [ ] 10µF ceramic at XT30 (C2)
- [ ] Pi heatsink in the build (C3)
- [ ] Spare GPIOs broken out to header (C4)
- [ ] ERC clean, DRC clean, Gerbers viewed before upload

**When every box is checked, the design is frozen. Order the board. Stop changing things. Start building.**

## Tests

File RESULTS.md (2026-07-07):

# Philo — Results & Measured Performance

This separates **measured** results (actually observed on hardware) from
**pending** figures that require the assembled PCB + motors. Measured numbers are
reproducible with [`vision/rpi/benchmark.py`](vision/rpi/benchmark.py).

---

## Measured — Raspberry Pi 5 (8GB) + Logitech USB webcam + Arduino Uno

Bench setup: Pi 5 runs the vision/control stack (Python 3.12), USB webcam as the
camera, Arduino Uno standing in for the ESP32 (drives LEDs + OLED + ultrasonic
obstacle override). Measured 2026-06. The Arduino Uno was used as a temporary hardware interface because the custom PCB and ESP32 controller were being ordered. 

| Metric | Measured | Method |
|---|---|---|
| Person-following pipeline (YOLOv8n-pose, `imgsz=256`, pose-only) | **~14 FPS** sustained | `main.py` FPS counter, steady over several minutes |
| Full stack + ASL (YOLOv8n-pose **+** MediaPipe hands per frame) | **~7–11 FPS** | `main.py` FPS counter |
| Object-labeling model added (YOLOv8s @ `imgsz=640`) | **~0.3 FPS** | inferred from ~15 s gesture lag; why the object model is **off by default** on the Pi |
| Gesture-stop response latency | **~0.35 s** | 5-frame confirmation ÷ 14 FPS |
| **ASL classifier — held-out test accuracy** | **99.0%** (26 classes; stratified 80/20 split, 2,349 unseen test samples) | `asl_from_dataset.py --csv asl_features.csv --eval` |
| ASL training set | **11,742 samples** (13,000 dataset images; 1,258 with no detectable hand skipped) | Kaggle ASL Alphabet dataset |
| ASL model | MediaPipe hand landmarks → scale-invariant features → scikit-learn MLP (256×128) | landmark-based (runs in real time on the Pi) |
| ASL live confidence (distinct letters) | **0.94 – 1.00** | live softmax probability on the Pi (per-hand) |

> Note: 99.0% is the held-out test accuracy on the Kaggle dataset (same distribution).
> Live webcam accuracy on a new user runs lower (distribution shift; C/O are naturally
> similar handshapes) — distinct letters are reliable, near-identical pairs less so.
| Pi → Arduino link | **115200 baud**, `STATUS` telemetry at **10 Hz** | protocol, verified live |
| Obstacle override threshold | **20 cm** (LED + OLED "STOP" fire within threshold, independent of camera) | firmware + live bench test |

**Key engineering result:** dropping the second (object-detection) model and
lowering `imgsz` 320→256 took the Pi from **~0.3 FPS to ~14 FPS** (~45×) — the
difference between an unusable ~15 s gesture lag and a ~0.35 s response.

## Verified in design (pre-bring-up, provable now)

| Item | Result | Evidence |
|---|---|---|
| Schematic / PCB | ERC clean, DRC clean, Gerbers exported | KiCad build log, June 21 |
| Motor driver choice | TB6612FNG over L298N | eliminates ~2 V bridge drop, no heatsink — real tradeoff |
| Camera geometry | 380 mm mount height, 25° upward tilt | trig-derived to frame knee→above-head at 1.5 m |
| Safety thresholds | 500 ms watchdog, 20–30 cm obstacle stop, 30° tilt cutoff | firmware, compiles clean |

## Pending hardware bring-up (targets — not yet measured)

These need the assembled board + motors and will be filled in with real numbers
after bring-up:

- **PID gains** (starting point Kp=1.0, Ki=0.1, Kd=0.05) — tune on the bench
- **Motor stall / running current** per channel
- **Camera → wheel-response latency** (end-to-end, stopwatch/logged)
- **Battery runtime** and full-load power draw

## Reproduce the measured numbers

On the Pi (3.12 env), no Arduino needed:
```bash
~/philo312/bin/python vision/rpi/benchmark.py --webcam --frames 300        # following FPS + per-stage ms
~/philo312/bin/python vision/rpi/benchmark.py --webcam --frames 300 --asl  # add MediaPipe timing
```
The script reports sustained FPS and mean/median/min/max latency for each stage
(camera grab, YOLO-pose, MediaPipe, total loop).

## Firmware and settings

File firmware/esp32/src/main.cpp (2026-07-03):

#include <Arduino.h>
#include <Wire.h>
#include <math.h>

#include "pins.h"
#include "motors.h"
#include "encoders.h"
#include "ultrasonic.h"
#include "imu.h"
#include "display.h"
#include "pi_comm.h"

// ── Safety / timing parameters ───────────────────────────────────────────────
#define WATCHDOG_MS        500    // stop if no CMD from the Pi for this long
#define US_INTERVAL_MS      60    // one sensor per slot — 40 kHz crosstalk guard
#define OBSTACLE_STOP_CM    25    // center sensor: hard stop under this
#define OBSTACLE_VEER_CM    30    // side sensors: veer away under this
#define SENSOR_HOLDOFF       3    // invalid readings in a row → assume blocked
#define TILT_LIMIT_DEG      30    // tip-over cutoff
#define ASL_SHOW_MS       2000    // how long an ASL letter owns the OLED
#define STATUS_MS          100    // telemetry rate (10 Hz)

static float    dist_cm[3]     = {400, 400, 400};   // L, C, R — last valid
static uint8_t  invalid_cnt[3] = {0, 0, 0};
static uint8_t  us_idx         = 0;

static PiCmd    last_cmd       = {0, 0, 1};   // boot state: coast-stopped
static uint32_t last_cmd_ms    = 0;
static bool     tilted         = false;
static uint32_t asl_until_ms   = 0;

static float read_vbat() {
    uint32_t raw = analogRead(PIN_VBAT);
    float vadc = (raw / ADC_FULL) * ADC_VREF;
    return vadc * VBAT_RATIO;
}

// 9 SCL pulses with SDA released — frees a slave left holding SDA low after a
// reset mid-transaction. Must run BEFORE Wire.begin.
static void i2c_bus_recovery() {
    pinMode(PIN_SDA, INPUT_PULLUP);
    pinMode(PIN_SCL, OUTPUT);
    for (int i = 0; i < 9; i++) {
        digitalWrite(PIN_SCL, HIGH);
        delayMicroseconds(5);
        digitalWrite(PIN_SCL, LOW);
        delayMicroseconds(5);
    }
    digitalWrite(PIN_SCL, HIGH);
    pinMode(PIN_SCL, INPUT_PULLUP);
}

// Fire ONE sensor per 60 ms slot, round-robin. All three share 40 kHz — firing
// together makes each hear the others' pulses as phantom near-range echoes.
static void update_ultrasonic() {
    static uint32_t last_ping_ms = 0;
    uint32_t now = millis();
    if (now - last_ping_ms < US_INTERVAL_MS) return;
    last_ping_ms = now;

    float d = (us_idx == 0) ? ultrasonic_left()
            : (us_idx == 1) ? ultrasonic_center()
                            : ultrasonic_right();

    if (d < 2.0f || d > 400.0f) {
        // Timeout / out of range: hold the last valid reading briefly, then
        // fail safe by assuming an obstacle at 20 cm.
        if (invalid_cnt[us_idx] < SENSOR_HOLDOFF) invalid_cnt[us_idx]++;
        if (invalid_cnt[us_idx] >= SENSOR_HOLDOFF) dist_cm[us_idx] = 20.0f;
    } else {
        dist_cm[us_idx] = d;
        invalid_cnt[us_idx] = 0;
    }
    us_idx = (us_idx + 1) % 3;
}

// Priority: tilt > watchdog > brake/coast flags > obstacle override > Pi cmd
static void apply_drive() {
    if (tilted)                             { motors_stop(); return; }
    if (millis() - last_cmd_ms > WATCHDOG_MS) { motors_stop(); return; }

    if (last_cmd.flags & 0x02) { motors_brake(); return; }
    if (last_cmd.flags & 0x01) { motors_stop();  return; }

    int  l = last_cmd.left;
    int  r = last_cmd.right;
    bool forward = (l > 0 || r > 0);

    if (forward) {
        if (dist_cm[1] < OBSTACLE_STOP_CM) { motors_stop(); return; }
        // Veer AWAY from a side obstacle. The robot turns toward its slower
        // side, so slow the side OPPOSITE the obstacle.
        if      (dist_cm[0] < OBSTACLE_VEER_CM) r = (r * 3) / 5;  // left blocked → turn right
        else if (dist_cm[2] < OBSTACLE_VEER_CM) l = (l * 3) / 5;  // right blocked → turn left
    }
    motor_set(l, r);
}

void setup() {
    Serial.begin(115200);
    pinMode(PIN_LED, OUTPUT);
    digitalWrite(PIN_LED, HIGH);   // LED on during init

    i2c_bus_recovery();
    Wire.begin(PIN_SDA, PIN_SCL);

    motors_init();
    encoders_init();
    ultrasonic_init();

    analogReadResolution(ADC_BITS);
    analogSetAttenuation(ADC_11db);  // full-scale ≈ 3.3 V

    if (!imu_init())      Serial.println("IMU not found – check I2C wiring");
    if (!display_init())  Serial.println("OLED not found – check I2C wiring");

    pi_comm_init(115200);

    Serial.println("Philo ready");
    digitalWrite(PIN_LED, LOW);
}

void loop() {
    static uint32_t last_status_ms = 0;

    // 1. Messages from the Pi
    PiCmd cmd;
    char  letter = 0;
    switch (pi_comm_recv(cmd, letter)) {
        case PI_MSG_CMD:
            last_cmd    = cmd;
            last_cmd_ms = millis();
            break;
        case PI_MSG_ASL:
            display_asl(letter);
            asl_until_ms = millis() + ASL_SHOW_MS;
            break;
        default:
            break;
    }

    // 2. Sensors
    update_ultrasonic();

    // 3. Drive through the safety priority chain (every pass, so the
    //    watchdog fires even when the Pi goes completely silent)
    apply_drive();

    // 4. Telemetry + display at 10 Hz
    uint32_t now = millis();
    if (now - last_status_ms >= STATUS_MS) {
        last_status_ms = now;

        PhiloStatus st{};
        st.vbat = read_vbat();
        st.dl   = dist_cm[0];
        st.dc   = dist_cm[1];
        st.dr   = dist_cm[2];
        st.el   = encoder_left();
        st.er   = encoder_right();

        ImuData imu{};
        if (imu_read(imu)) {
            st.ax = imu.ax;
            st.ay = imu.ay;
            st.az = imu.az;
            st.gz = imu.gz;

            // Tip-over: angle between the gravity vector and the board Z axis
            // (MPU mounted flat). Clears automatically once righted.
            float mag = sqrtf(imu.ax * imu.ax + imu.ay * imu.ay + imu.az * imu.az);
            if (mag > 0.5f) {
                float tilt_deg = acosf(fabsf(imu.az) / mag) * 180.0f / PI;
                tilted = (tilt_deg > TILT_LIMIT_DEG);
            }
        }

        pi_comm_send(st);

        // An ASL letter owns the screen for 2 s, then telemetry resumes
        if ((int32_t)(now - asl_until_ms) >= 0)
            display_status(st.vbat, st.dl, st.dc, st.dr, st.el, st.er);
    }
}

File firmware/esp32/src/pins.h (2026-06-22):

#pragma once

// ── Motor control ────────────────────────────────────────────────────────────
// U6 (front) and U7 (rear) share the same control lines.
// A-channel drives left wheels, B-channel drives right wheels.
#define PIN_PWM_L   25   // IO25  → U6/U7 PWMA
#define PIN_L_IN1   26   // IO26  → U6/U7 AIN1
#define PIN_L_IN2   27   // IO27  → U6/U7 AIN2

#define PIN_PWM_R   32   // IO32  → U6/U7 PWMB
#define PIN_R_IN1   33   // IO33  → U6/U7 BIN1
#define PIN_R_IN2   14   // IO14  → U6/U7 BIN2

// ── Encoders ─────────────────────────────────────────────────────────────────
// GPIO34/35 are input-only; no internal pull-up/down available.
#define PIN_ENC_L   34   // IO34
#define PIN_ENC_R   35   // IO35

// ── Ultrasonic (HC-SR04) ─────────────────────────────────────────────────────
// ECHO signals are 5 V; voltage dividers (R3/R7, R1/R2, R8/R9) drop to 3.3 V.
#define PIN_TRIG_L  19   // IO19
#define PIN_ECHO_L   4   // IO4

#define PIN_TRIG_C   5   // IO5
#define PIN_ECHO_C  18   // IO18

#define PIN_TRIG_R  13   // IO13
#define PIN_ECHO_R  23   // IO23

// ── I²C (MPU-6050 @ 0x68, OLEDs via J_MAST) ─────────────────────────────────
#define PIN_SDA     21   // IO21
#define PIN_SCL     22   // IO22

// ── UART to Raspberry Pi (J6) ─────────────────────────────────────────────────
#define PIN_ESP_TX  17   // IO17  → Pi RX
#define PIN_ESP_RX  16   // IO16  → Pi TX

// ── Analog ───────────────────────────────────────────────────────────────────
// Divider: R5=10 kΩ from VBAT, R6=3.3 kΩ to GND
// Vsense = Vbat × 3.3/13.3  →  Vbat = Vsense × 13.3/3.3
#define PIN_VBAT    36   // SENSOR_VP / ADC1_CH0
#define VBAT_RATIO  (13.3f / 3.3f)
#define ADC_BITS    12
#define ADC_FULL    4095.0f
#define ADC_VREF    3.3f

// ── Misc ──────────────────────────────────────────────────────────────────────
#define PIN_LED      2   // IO2  – status LED via R11 (100 Ω)
#define PIN_BOOT     0   // IO0  – BOOT/SW2, pulled high via R12 (10 kΩ)

// ── LEDC PWM ──────────────────────────────────────────────────────────────────
#define PWM_CH_L     0
#define PWM_CH_R     1
#define PWM_FREQ     20000   // 20 kHz – inaudible
#define PWM_BITS     8       // duty 0–255

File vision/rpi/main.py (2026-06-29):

"""
Philo combined vision stack:
  - Person following   (YOLOv8n-pose → bounding box)
  - Gesture stop       (wrist above shoulder for 5 frames)
  - ASL recognition    (MediaPipe hands → trained classifier)

Usage:
  python main.py --webcam                     laptop, no hardware
  python main.py --webcam --serial COM3       laptop + Arduino
  python main.py                              Pi camera
  python main.py --serial /dev/serial0        Pi + ESP32

Controls: Q to quit (window must be focused)
"""

import argparse
import math
import os
import pickle
import time
import urllib.request

import cv2

# MediaPipe is only needed for ASL. It has no wheel for some Python versions
# (e.g. 3.13 on the Pi), so make it optional — person-following works without it.
try:
    import mediapipe as mp
    HAS_MEDIAPIPE = True
except ImportError:
    HAS_MEDIAPIPE = False

from tracker import PoseTracker
from controller import PhiloController
from asl_features import landmarks_to_features

FRAME_W, FRAME_H = 640, 480
ASL_SKIP        = 2          # run ASL every N frames (keeps loop fast)
ASL_CONFIRM     = 5          # frames same letter must appear before sending
ASL_COOLDOWN    = 2.0        # seconds before re-sending same letter

MODEL_PATH = "hand_landmarker.task"
MODEL_URL  = (
    "https://storage.googleapis.com/mediapipe-models/"
    "hand_landmarker/hand_landmarker/float16/1/hand_landmarker.task"
)
ASL_MODEL_FILE = "asl_model.pkl"


# ── camera ────────────────────────────────────────────────────────────────────

def open_camera(use_webcam, source=None):
    # --source: a stream URL (e.g. http://169.254.x.x:8080/video) or a device index
    if source is not None:
        src = int(source) if str(source).isdigit() else source
        return cv2.VideoCapture(src)
    if use_webcam:
        cap = cv2.VideoCapture(0)
        cap.set(cv2.CAP_PROP_FRAME_WIDTH, FRAME_W)
        cap.set(cv2.CAP_PROP_FRAME_HEIGHT, FRAME_H)
        return cap
    from picamera2 import Picamera2
    cam = Picamera2()
    cam.configure(cam.create_preview_configuration(
        main={"format": "RGB888", "size": (FRAME_W, FRAME_H)}
    ))
    cam.start()
    return cam


def grab_frame(cap, use_webcam):
    if use_webcam:
        ok, frame = cap.read()
        return frame if ok else None
    return cap.capture_array()


# ── ASL helpers ───────────────────────────────────────────────────────────────

def download_hand_model():
    if not os.path.exists(MODEL_PATH):
        print("Downloading hand landmarker model (~25MB)...")
        urllib.request.urlretrieve(MODEL_URL, MODEL_PATH)
        print("Done.")


def create_landmarker():
    options = mp.tasks.vision.HandLandmarkerOptions(
        base_options=mp.tasks.BaseOptions(model_asset_path=MODEL_PATH),
        running_mode=mp.tasks.vision.RunningMode.IMAGE,
        num_hands=1,
        min_hand_detection_confidence=0.7,
    )
    return mp.tasks.vision.HandLandmarker.create_from_options(options)


def hand_features(result):
    if not result.hand_landmarks:
        return None
    return landmarks_to_features(result.hand_landmarks[0])


def draw_hand(frame, result):
    if not result.hand_landmarks:
        return
    h, w = frame.shape[:2]
    for hand in result.hand_landmarks:
        pts = [(int(lm.x * w), int(lm.y * h)) for lm in hand]
        for pt in pts:
            cv2.circle(frame, pt, 4, (255, 100, 0), -1)
        for a, b in [(0,1),(1,2),(2,3),(3,4),(0,5),(5,6),(6,7),(7,8),
                     (0,9),(9,10),(10,11),(11,12),(0,13),(13,14),(14,15),(15,16),
                     (0,17),(17,18),(18,19),(19,20),(5,9),(9,13),(13,17)]:
            cv2.line(frame, pts[a], pts[b], (200, 80, 0), 2)


# ── overlay ───────────────────────────────────────────────────────────────────

OBSTACLE_CM = 20   # matches the Arduino's OBSTACLE_CM


def draw_overlay(frame, bbox, labels, stopped, asl_letter, status=None):
    if bbox is not None:
        x1, y1, x2, y2 = map(int, bbox)
        color = (0, 0, 255) if stopped else (0, 255, 0)
        cv2.rectangle(frame, (x1, y1), (x2, y2), color, 2)

    for (lx1, ly1, lx2, ly2, name, conf) in labels:
        cv2.rectangle(frame, (lx1, ly1), (lx2, ly2), (255, 165, 0), 2)
        cv2.putText(frame, f"{name} {conf:.0%}", (lx1, ly1 - 6),
                    cv2.FONT_HERSHEY_SIMPLEX, 0.5, (255, 165, 0), 2)

    status_text = "GESTURE STOP" if stopped else "FOLLOWING"
    cv2.putText(frame, status_text, (10, 32),
                cv2.FONT_HERSHEY_SIMPLEX, 0.9, (0, 255, 255), 2)

    if asl_letter:
        cv2.putText(frame, f"ASL: {asl_letter}", (10, 70),
                    cv2.FONT_HERSHEY_SIMPLEX, 1.2, (255, 80, 200), 3)

    # ── telemetry returned from the ESP32/Arduino (closes the loop) ──
    if status is not None:
        dc = status.get("dc", 999)
        vbat = status.get("vbat", 0)
        cv2.putText(frame, f"ESP dist: {int(dc)}cm   vbat: {vbat:.1f}V",
                    (10, frame.shape[0] - 15),
                    cv2.FONT_HERSHEY_SIMPLEX, 0.6, (200, 200, 200), 2)
        if 0 < dc < OBSTACLE_CM:
            cv2.putText(frame, "!! OBSTACLE - ROBOT OVERRIDE STOP !!",
                        (10, frame.shape[0] - 45),
                        cv2.FONT_HERSHEY_SIMPLEX, 0.7, (0, 0, 255), 2)


# ── main ──────────────────────────────────────────────────────────────────────
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

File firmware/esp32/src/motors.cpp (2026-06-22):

#include "motors.h"
#include "pins.h"

void motors_init() {
    pinMode(PIN_L_IN1, OUTPUT);
    pinMode(PIN_L_IN2, OUTPUT);
    pinMode(PIN_R_IN1, OUTPUT);
    pinMode(PIN_R_IN2, OUTPUT);

    ledcSetup(PWM_CH_L, PWM_FREQ, PWM_BITS);
    ledcAttachPin(PIN_PWM_L, PWM_CH_L);
    ledcSetup(PWM_CH_R, PWM_FREQ, PWM_BITS);
    ledcAttachPin(PIN_PWM_R, PWM_CH_R);

    motors_stop();
}

static void drive_side(uint8_t in1, uint8_t in2, uint8_t ch, int speed) {
    speed = constrain(speed, -255, 255);
    if (speed > 0) {
        digitalWrite(in1, HIGH);
        digitalWrite(in2, LOW);
        ledcWrite(ch, (uint8_t)speed);
    } else if (speed < 0) {
        digitalWrite(in1, LOW);
        digitalWrite(in2, HIGH);
        ledcWrite(ch, (uint8_t)(-speed));
    } else {
        digitalWrite(in1, LOW);
        digitalWrite(in2, LOW);
        ledcWrite(ch, 0);
    }
}

void motor_set(int left_speed, int right_speed) {
    drive_side(PIN_L_IN1, PIN_L_IN2, PWM_CH_L, left_speed);
    drive_side(PIN_R_IN1, PIN_R_IN2, PWM_CH_R, right_speed);
}

void motors_stop() {
    motor_set(0, 0);
}

void motors_brake() {
    digitalWrite(PIN_L_IN1, HIGH);
    digitalWrite(PIN_L_IN2, HIGH);
    ledcWrite(PWM_CH_L, 255);

    digitalWrite(PIN_R_IN1, HIGH);
    digitalWrite(PIN_R_IN2, HIGH);
    ledcWrite(PWM_CH_R, 255);
}

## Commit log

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2026-06-17 docs: add hardware README — PCB blocks, sensors, obstacle avoidance
2026-06-17 docs: add firmware README — motor control, PID, UART protocol, gesture response
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2026-06-17 docs(mechanical): add weight budget, motor torque math, CG rules, print orientation guidance
2026-06-17 fix(hardware): replace MP2307 with MP1584EN (3A), add power budget, runtime estimate, trace width table, voltage divider detail
2026-06-17 docs(mechanical): add verified component weights, torque math with real specs, CG analysis, print failure modes
2026-06-17 docs(hardware): add verified component specs, 10 failure modes with mitigations, real power budget, trace width table, battery sense circuit
2026-06-17 docs(hardware): add ground plane strategy, bulk caps, transient analysis, stress test protocol, brownout visibility
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2026-06-17 docs: add companion eyes + audio (Pi-side) to hardware/README.md; lock 2S battery
2026-06-17 docs: add companion eyes + audio (Pi-side) to firmware/README.md; lock 2S battery
2026-06-17 docs: add companion eyes + audio (Pi-side) to vision/README.md; lock 2S battery
2026-06-17 docs: add companion eyes + audio (Pi-side) to PRE_BUILD_LOCK.md; lock 2S battery
2026-06-17 docs: add BOM + schematic build plan; fix motor channel wiring (hardware/BOM.md)
2026-06-17 docs: add BOM + schematic build plan; fix motor channel wiring (hardware/SCHEMATIC.md)
2026-06-17 docs: add BOM + schematic build plan; fix motor channel wiring (hardware/README.md)
2026-06-17 docs: add BOM + schematic build plan; fix motor channel wiring (firmware/README.md)
2026-06-17 fix: correct P-FET reverse-protection orientation (drain=battery, source=load)
2026-06-17 hw: upgrade 5V rail to Pololu D24V50F5 (5A) for Pi headroom (hardware/README.md)
2026-06-17 hw: upgrade 5V rail to Pololu D24V50F5 (5A) for Pi headroom (hardware/BOM.md)
2026-06-17 hw: upgrade 5V rail to Pololu D24V50F5 (5A) for Pi headroom (hardware/SCHEMATIC.md)
2026-06-17 hw: upgrade 5V rail to Pololu D24V50F5 (5A) for Pi headroom (PRE_BUILD_LOCK.md)
2026-06-18 Add completed Philo schematic - ERC clean, all footprints assigned
    [POWER.kicad_sch, Philo.kicad_pcb, Philo.kicad_sch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]
2026-06-18 Move KiCad files to hardware/kicad/, update docs for completed schematic
    Moved all KiCad project files from repo root into hardware/kicad/.
    Updated BOM.md with correct post-annotation ref designators (U6/U7 TB6612FNG,
    U8 ESP32, U5 AMS1117, U1 MPU-6050, Q2 P-MOSFET, F2 polyfuse).
    Updated README.md checklist: all schematic items checked, week 1-2 marked DONE,
    current phase noted as PCB layout. Schematic: 0 ERC errors, footprints assigned.
    [POWER.kicad_sch, Philo.kicad_pcb, Philo.kicad_sch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]
2026-06-22 Add completed PCB layout for Philo robot
    - Full component placement on 100x100mm 2-layer board
    - All 169 connections routed (0 unconnected pads)
    - GND copper pour on both F.Cu and B.Cu
    - Net classes: VBAT=2.5mm, +5V=1.5mm, +3V3=0.8mm, signals=0.25mm
    - DRC clean: 0 errors, 0 unconnected, silk warnings only
    - ESP32 antenna keep-out zone maintained
    - Ready for Gerber export and JLCPCB fabrication
    [Philo- main.kicad_pcb]
2026-06-22 Fix U1 ref designator in schematic — sync with PCB
    Changed GY-521 8-pin header from J15 → U1 to match PCB.
    Symbol was re-annotated when MPU-6050 was replaced with
    Connector_Generic:Conn_01x08 during crash recovery session.
    [Philo.kicad_sch]
2026-06-22 Add ESP32 firmware skeleton with all subsystem modules
    PlatformIO project for ESP32-WROOM-32. GPIO assignments verified
    from KiCad netlist export. Includes motors, encoders, 3x ultrasonic,
    MPU-6050 IMU, SSD1306 OLED, and Pi UART communication.
2026-06-22 Reorganise repo — all files in proper folders, add gerbers and STEP
    - Move PCB files (Philo- main.*) from root → hardware/kicad/
    - Move DRC.rpt from root → hardware/kicad/
    - Move PRE_BUILD_LOCK.md from root → docs/
    - Add 3D STEP export → mechanical/
    - Add Gerber/drill files → hardware/kicad/gerbers/
    - Add schematic project settings files (Philo- schematic.kicad_pro/prl)
    - Update .gitignore: cover autosave files, borh/ working folder, OS junk
    - Fix platformio.ini: pin to espressif32@6.9.0 (fixes pins_arduino.h build error)
    - Fix motors.cpp: use Arduino 2.x LEDC API (ledcSetup/ledcAttachPin/ledcWrite)
    - Update README: correct folder tree, mark schematic/PCB/firmware as done
    Co-Aut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
    [Philo- main-B_Cu.gbl, Philo- main-B_Mask.gbs, Philo- main-B_Paste.gbp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]
2026-06-23 Add Raspberry Pi vision stack + bench-test firmware
    Vision (vision/rpi/): person following (YOLOv8n-pose), gesture stop,
    object labels, and ASL fingerspelling (MediaPipe + trained classifier).
    Shared scale-invariant feature extraction (asl_features.py) keeps training
    and inference in sync and fixes the dataset-crop vs webcam size mismatch.
    Firmware: Arduino Uno stand-in (LED + SSD1306 OLED) and experimental Pico
    MicroPython scripts for bench testing the CMD/STATUS/ASL serial protocol.
    [arduino_philo.ino, asl_collect.py, asl_features.py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]
2026-06-23 docs: align serial protocol across all READMEs with implemented firmware
    The firmware (pi_comm.cpp / motors.h) and the Pi code use numeric
    differential-drive commands: CMD <left> <right> <flags> (-255..255).
    Several docs still described an older CMD:<direction>,<speed> format
    (CMD:F,150) plus a MOOD:/OLED-eyes companion feature that no firmware
    parses yet. Integration code written against those docs would not work.
    - vision/README.md: command-translation, gesture, and no-person blocks
    now emit numeric CMD; added a canonical Serial Protocol section; marked
    the eye-mood (MOOD:) feature as PLANNED; reconciled the file list with
    the actual vision/rpi/ files.
    - firmware/README.md: Serial P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
2026-06-24 Bench test sketches + turn-signal receiver; fix stale motor/buck in README
    Firmware (firmware/arduino/):
    - arduino_philo.ino: add left/right turn-indicator LEDs (D7/D8) and OLED
    direction readout alongside the follow LED (D6) and ASL letter display.
    - Add bench bring-up sketches: i2c_scan, test_oled, test_mpu_oled,
    test_ultrasonic_oled, test_led, sensor_min, sensor_hub. All validated on
    the breadboard (OLED 0x3C + MPU-6050 0x68 + HC-SR04 + LED).
    Docs:
    - README.md parts table: corrected two stale entries that contradicted the
    authoritative hardware/BOM.md — drive motors are JGA25-370 (6V 200RPM),
    not N20 (12V); 5V buck is the Pololu D24V50F5 (5A), not the MP2307.
    Updated rough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
    [arduino_philo.ino, i2c_scan.ino, sensor_hub.ino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]
2026-06-24 Fix stale 5A polyfuse references in hardware/README -- align to 7A (BOM is authoritative)
    Update trip-timing analysis: RGEF700 at 8.8A stall is 1.26x hold,
    trips slowly (minutes). Firmware 500ms watchdog is primary stall
    protection; polyfuse is last-resort firmware-crash backstop.
2026-06-24 Full doc audit: fix inconsistencies across all READMEs
    - Root README: 65mm wheels -> 80mm (matches mechanical spec + torque math)
    - Root README: fix DISCLAMER typo, rewrite ASL note more clearly
    - Root README: status checklist updated -- mark vision stack, gesture, ASL
    as done on bench; add gesture sensitivity as open item (issue #2)
    - firmware/README: motor.cpp -> motors.cpp (correct filename)
    - firmware/README: pin note updated -- pins are final, not draft
    - firmware/README: timeline rewritten to reflect firmware skeleton complete
    - vision/README: gesture section notes known sensitivity issue -> issue #2
    - hardware/README: power budget motor row clarifies polyfuse + watchdog
    Co-Authored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
2026-06-25 Add obstacle safety override + bidirectional STATUS telemetry
    Closes the sensor loop on the bench setup:
    - arduino_philo.ino now reads its own HC-SR04 and forces STOP when an obstacle
    is within 20cm, overriding the laptop's follow command — the safety layer
    runs on the microcontroller and does not depend on the link (mirrors the real
    ESP32 priority override). Also streams STATUS back at 10Hz.
    - main.py displays the returned distance + a red "OBSTACLE - OVERRIDE STOP"
    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
2026-06-28 Add Pi->Arduino link test script (vision/rpi/test_link.py)
    Auto-detects the Arduino on /dev/ttyACM* and runs a follow/turn/stop
    sequence so the LEDs + OLED can be verified without a camera. Used to
    confirm the Pi drives the Arduino once the Pi became the controller.
2026-06-28 Add --source (network stream) to main.py + laptop webcam_stream.py
    Lets the Pi use a remote camera over the direct Ethernet link: the laptop
    runs webcam_stream.py (MJPEG over HTTP, stdlib only) and the Pi runs
    main.py --source http://<laptop-ip>:8080/video. Works around having no
    USB webcam on the Pi yet. --source accepts a stream URL or device index.
2026-06-29 Big Pi speedup: drop object-detection model by default, smaller imgsz, FPS readout
    The object-labeling model (yolov8s @ 640) ran every frame alongside the pose
    model — fine on a laptop, far too heavy on the Pi (~0.3 FPS, ~15s gesture lag).
    - PoseTracker now runs pose-only by default (enable_objects=False); the heavy
    detect model isn't even loaded unless --objects is passed (laptop only).
    - Pose imgsz 320 -> 256.
    - main.py prints an FPS readout every 3s so we can measure.
    [main.py, tracker.py]
2026-06-29 main.py: don't crash if ASL model fails to load (fall back to following)
    [main.py]
2026-06-29 asl_from_dataset.py: add --csv mode (extract on one machine, train on another)
    Fixes cross-version pickle errors: a model trained on the laptop (Py3.13/numpy2)
    can't unpickle on the Pi (Py3.12/numpy1). Now extraction (--dataset) also writes
    a version-independent asl_features.csv; --csv trains from that CSV so the model
    is built with the running machine's own numpy/sklearn. Extraction deps (cv2,
    mediapipe) are lazy-imported so --csv works without them.
    [asl_from_dataset.py]
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2026-06-29 Add Xbox controller manual drive (--manual) + clean stop on quit
    gamepad.py: pygame Xbox reader (left stick arcade drive, A=toggle), headless.
    main.py: --manual enables it; A flips AUTO (follow) <-> MANUAL (left stick drives).
    MANUAL skips YOLO to save CPU; obstacle override still runs on the Arduino.
    Loop now wrapped in try/finally so the robot always gets a STOP command on Ctrl+C.
    Removed the per-frame ASL debug print (console spam).
    [gamepad.py, main.py]
2026-06-29 docs: bring vision/rpi README up to date (Pi 5 brain, manual drive, ASL on 3.12)
    Reflects current reality: runs on Pi 5 (or laptop), USB webcam, Xbox manual
    drive (--manual), obstacle override, the two Pi venvs (3.13 follow-only and
    3.12 full+ASL), CSV-based cross-machine ASL training, performance numbers,
    and the new files (gamepad, test_link, webcam_stream, gamepad_test).
2026-06-29 BOM: add OLED spec, price, and source -- 2x SSD1306 0.96in I2C
2026-06-29 Upgrade Pi 4 -> Pi 5 across all docs; note 5V rail is near capacity
    Pi 5 with active cooler on hand. Power budget updated: 3.5A typical,
    4.5A peak vs Pi 4's 2.5A/3.0A. D24V50F5 at 5A is near limit -- flagged
    in BOM, hardware README, and component spec table. Weight updated +20g.
2026-06-30 Comprehensive 3-round doc audit -- fix all stale refs and missing parts
    README: Pi 4 -> Pi 5 in What It Does text and ASCII diagram
    README: Add OLEDs, polyfuse, MOSFET, LED, switches, large electrolytic
    caps to hardware table (were all missing); TB6612FNG source Adafruit ->
    DigiKey (bare SSOP-24 IC); total $180 -> $200; budget $150 -> $200
    hardware/BOM: status Ready for PCB layout -> Ready to order; all
    Off-Board Modules rows get Est. Price + Notes columns (broken/missing);
    Pi Camera v2 -> Camera Module 3; electrolytic caps get 16V ratings
    hardware/README: phase -> PCB fabrication; fix D24V50F5 table (extra col
    was breaking render); Pi 5 power numbers corrected (3.5A/4.5A); failure
    mode 10 P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
2026-07-03 Full repo audit: verify firmware builds, refresh stale ERC/DRC, honest status
    Verified working:
    - ESP32 firmware compiles clean (PlatformIO, 7% RAM / 25% flash)
    - All 14 Python files pass syntax check
    - Fresh ERC on current schematic: 0 errors (checked-in report was a stale
    June 17 mid-design snapshot showing 14 errors -- regenerated)
    - Fresh DRC on current board: 0 errors, 57 cosmetic silkscreen warnings
    (regenerated report checked in)
    Fixes:
    - firmware/README: Responsibilities table now shows real implementation
    status -- watchdog, obstacle override, tilt cutoff, ASL handler are
    bench-rig-only or not yet ported to ESP32; added honest status note
    - README: ASL OLED display clarifie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
    [asl_from_dataset.py]
2026-07-03 Implement ESP32 safety layer -- watchdog, obstacle override, tilt cutoff
    Firmware (compiles clean, awaiting PCB bring-up):
    - 500ms command watchdog: motors stop if the Pi goes silent; checked on
    every loop pass via apply_drive() priority chain
    - Obstacle override: center < 25cm while moving forward -> hard stop;
    side < 30cm -> veer away by slowing the side OPPOSITE the obstacle
    (the old doc pseudo-code had the sides swapped -- it would have
    steered INTO the obstacle; doc fixed to match)
    - Sequential ultrasonic firing: one sensor per 60ms slot, round-robin,
    per the documented 40kHz crosstalk requirement; invalid readings hold
    last-valid for 3 cycles then fail safe to obstacle-at-2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
    [main.cpp, pi_comm.cpp, ultrasonic.cpp]
2026-07-06 Add RESULTS.md (measured Pi 5 performance) + benchmark.py
    Real numbers measured on the Pi 5 + USB webcam + Arduino bench this session:
    ~14 FPS person-following (YOLOv8n-pose, imgsz 256), ~7-11 FPS with MediaPipe ASL,
    ~0.3 FPS with the object model (why it's off), ASL 0.94-1.00 confidence, 11,742
    training samples, loss 1.63->0.0016. RESULTS.md honestly separates measured from
    pending-hardware-bring-up (PID, motor current, drive latency). benchmark.py
    reproduces the FPS + per-stage latency numbers.
2026-07-06 asl_from_dataset.py: add --eval (held-out test accuracy, 80/20 stratified split)
    Gives a real, measured classification accuracy (+ per-class report) instead of
    only training loss — for honest reporting.
2026-07-06 RESULTS.md: add measured ASL held-out test accuracy (99.0%, 26 classes)
    Measured via asl_from_dataset.py --eval (stratified 80/20, 2,349 test samples).
    Notes the honest distinction between dataset test accuracy and live-webcam use.
2026-07-07 Grow PCB to 116x116mm to add 4x real M3 mounting holes
    The original 100x100mm layout had zero edge clearance, no room for
    mounting holes anywhere except a cramped middle area. Grew the board
    outline outward by about 8mm per side, all existing components and
    routing left at their original coordinates, nothing re-routed, and
    placed 4x MountingHole_3.2mm_M3 footprints in the new corner margin.
    Verified with kicad-cli: ERC 0 errors, DRC 0 errors, 56 cosmetic
    silkscreen-clipped-by-mask warnings, same category as before the resize.
    Docs updated:
    - mechanical/README.md: real hole coordinates for the chassis plate
    standoffs, replaces the old placeholder note about hole positions
    - docs/PRE_BUILD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
    [Philo- main-B_Cu.gbl, Philo- main-B_Mask.gbs, Philo- main-B_Paste.gbp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]
2026-07-08 Revise ultrasonic sensor mount specifications
    Updated ultrasonic sensor mount details including angles and detection width calculations.
2026-07-09 Fix stale D24V50F5 price: BOM said ~$15, real price is $29.95
    Pololu lists it direct at $29.95 (5-pack: $27.55 ea). Total updated
    ~$200 to ~$215. Team decided to keep this part over a bare-IC or
    generic-module alternative, since the schematic/PCB are already fixed
    and about to be ordered, and the docs already document Pi brownout as
    the #1 demo-killer risk this regulator is sized to avoid.
2026-07-12 Add mechanical STL + STEP files for 3D printing (8 parts)
    Chassis, bottom plate, top, Pi case, C270 camera mount, JGA25-370 motor
    bracket, ultrasonic sensor cover, external mount. STL = print-ready;
    STEP = CAD interchange. (.f3d Fusion sources kept locally.)
    [Bottom Plate.step, Bottom Plate.stl, C270 Mount (1).step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]
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2026-10-15 Bench mode: USB command input and optional ultrasonic bypass
    Typed CMD lines were only read on the Pi UART (GPIO16/17), and with no
    sensors wired the timeout failsafe blocks all forward drive. PI_OVER_USB
    and NO_ULTRASONIC build flags fix both for laptop/bench testing.
    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
2026-10-15 Skip IMU reads when the IMU was not found
    Without an IMU the I2C reads returned stale garbage, which computed a
    bogus tilt angle and tripped the tip-over cutoff, blocking all motion.
    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
2026-10-15 Bench env: remap motor pins to dev-board bottom row, skip ultrasonic init
    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
2026-10-15 Fix follow speed: area thresholds assumed 320px frames
    YOLO returns boxes in original-frame pixels, so every person in a 640x480
    webcam frame read as 'very close' and the controller always sent its
    minimum speed (60/255), which only made the motors hum. Thresholds are now
    fractions of the frame area, use the real frame size, MIN_SPEED is 120,
    and --min-speed/--max-speed tune it. The FPS line now shows the last CMD
    sent and how many the ESP32 ACKed, to confirm the link.
    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
2026-10-15 asl_collect: use the shared feature code and unflipped frames
    It trained on unnormalized features from a mirrored image while main.py
    predicts on scale-invariant features from the raw image, so models it made
    gave wrong letters at runtime. Also refuse to train on a single letter
    (SVC needs two classes).
    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
2026-10-16 Split Bottom Plate into two dovetailed halves for smaller print beds
    Halves are 186x135 and 186x123 mm (fits a 220x220 bed). Half A has a
    dovetail tab on the centre pad; half B has the matching slot with 0.2 mm
    clearance. Two 30x40x3 splice plates bridge the side-rail seams.
    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
2026-10-16 N20 rim for LEGO tire 89201 (Ø24 x 14): scad + ready-made STL
    Tire 89201 is 18 mm ID / 24 mm OD / 14 mm wide (same as LEGO rim 55982),
    so the rim is an 18.3 mm seat with 19.6 mm edge lips and a 3 mm D-bore.
    Replaces the earlier groove-style hub that needed caliper measurements.
    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
